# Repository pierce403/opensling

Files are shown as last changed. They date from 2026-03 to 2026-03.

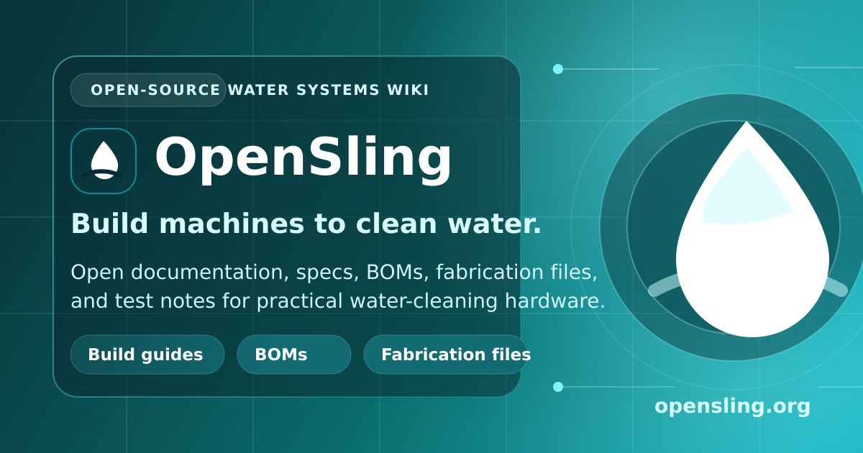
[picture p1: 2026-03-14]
docs/img/social-preview.png

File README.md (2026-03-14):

# OpenSling Wiki

OpenSling is an open documentation hub for designing, prototyping, and operating machines that clean water. This repo keeps the same MkDocs Material setup as `sloppy.wiki`, retargeted around modular treatment hardware, testing workflows, and field operations.

## Quick Start

```bash
source activate.sh
./serve.sh
```

The local site is served at `http://127.0.0.1:8000`.

To produce a deployable build:

```bash
./build.sh
```

## What This Wiki Covers

- treatment-train design for field-cleanable water systems
- mechanical and electrical architecture for modular treatment machines
- build guides for bench prototypes, pilot skids, and test rigs
- operational practices for sampling, maintenance, and safety
- research backlogs and sourcing notes for future iterations

## Repo Layout

- `mkdocs.yml`: site navigation, theme, and Markdown configuration
- `docs/`: wiki content and static assets
- `docs/css/custom-styles.css`: visual overrides for the OpenSling theme
- `.github/workflows/deploy.yml`: GitHub Actions deployment workflow
- `activate.sh`, `serve.sh`, `build.sh`: local development helpers

## Deployment

The workflow builds the site on every push to `main` and publishes it through the official GitHub Pages deployment flow. The intended public URL is:

`https://opensling.org`

## Licensing Model

OpenSling is meant to be copied and built from.

- documentation text, diagrams, tables, and educational media are licensed under `CC BY 4.0`
- code, scripts, configuration, and fabrication design sources are licensed under `Apache-2.0`

See `LICENSING.md`, `LICENSE`, and `LICENSE-docs.md`.

## License

Reuse is encouraged. Copy the docs, adapt them, fork the code, and build from the fabrication files within the license terms above.

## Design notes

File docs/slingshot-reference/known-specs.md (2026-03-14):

# Public Specs And Shared-Thread Notes

This page separates three different things:

1. public claims made by DEKA, Coca-Cola, Dartmouth, and WHO-linked reporting
2. working notes extracted from the shared ChatGPT thread you linked
3. OpenSling reconstruction choices made because the exact production design is not fully public

## What Is Publicly Documented

| Item | Shared-thread note | Public evidence | Assessment |
|---|---|---|---|
| Treatment method | Vapor-compression distillation / mechanical vapor recompression | DEKA says Slingshot uses <strong>vapor compression distillation</strong>.[^deka] | Verified |
| Water sources | “Any dirty water,” including sewage | Coca-Cola’s 2012 release says the system can boil and evaporate river water, ocean water, and raw sewage, then condense pure water.[^coke-2012] | Verified public claim |
| Output | Around <strong>1000 L/day</strong> or <strong>10 gal/hour</strong> | Coca-Cola’s 2012 release and Dartmouth’s 2014 article both repeat about <strong>10 gallons of clean water an hour</strong>; Coca-Cola also states <strong>up to 300,000 liters per year</strong>.[^coke-2012][^dartmouth] | Verified public claim |
| Power draw | Roughly <strong>500 W to under 1 kW</strong> | Dartmouth and Coca-Cola both say <strong>less than 1 kW</strong>; the shared thread also mentioned a secondary-report figure of <strong>500 W</strong>.[^coke-2012][^dartmouth][^share] | `<1 kW` is public; `500 W` should be treated as secondary-report territory |
| Physical scale | About the size of a mini-bar fridge | Dartmouth describes it as equal to a hotel mini-bar fridge.[^dartmouth] | Verified public claim |
| Maintenance posture | Few moving parts, low ongoing maintenance | Dartmouth and DEKA describe low moving-part count and low maintenance needs.[^dartmouth][^deka] | Verified public claim |
| Core evaporator geometry | Copper tubes with plastic dowels making a thin film | DEKA’s public Slingshot page states that the evaporator uses copper tubes with plastic dowels to form a thin film.[^deka] | Verified |
| Pressure lift | Compressor raises steam from <strong>7 psi to 9 psi</strong> | DEKA states this directly on the public Slingshot page.[^deka] | Verified |
| Power-source flexibility | Grid, batteries, solar, or Stirling generation | Coca-Cola’s 2012 release explicitly mentions grid, batteries, solar cells, and DEKA’s Stirling generator powered by biogas.[^coke-2012] | Verified public claim |

## What The Shared Thread Added

The shared thread is useful because it pushed the public record into a more build-oriented interpretation:

- It identified the Slingshot concept as a <strong>water-vapor heat pump</strong>, not simple one-pass boiling.
- It treated the pressure lift as a <strong>small differential</strong> that makes latent-heat recycling plausible.
- It emphasized a <strong>counterflow heat exchanger</strong>, <strong>mist elimination before compression</strong>, and <strong>blowdown handling</strong> as essential pieces of the open design.[^share]
- It argued that an exact under-`$2000`, full-scale clone is not credible, but a lower-throughput open reference machine is more realistic.[^share]

## Where The Shared Thread Was Inference

Some details in the thread are best treated as engineering hypotheses, not verified Slingshot facts:

| Thread claim | Why it matters | Current status |
|---|---|---|
| Regenerative blower as the default compressor | Drives motor selection, noise, and moisture tolerance | Reasonable inference, but not fully confirmed as the only public production implementation |
| 1.5-2 psi preferred differential across the blower | Critical for compressor sizing | Supported by patent-family reasoning in the thread, but not stated on DEKA’s public marketing page |
| Three parallel 100 ft stainless coils in a pressurized shell | Strongly shapes the open build | This is an OpenSling design proposal, not a public Slingshot bill of materials |
| 600-800 L/day baseline, 1000 L/day stretch for a practical open build | Useful for scoping fabrication and testing | OpenSling design target, not a historical Slingshot spec |

## OpenSling Position

OpenSling is not pretending to possess the hidden factory drawings for Slingshot. The approach here is:

1. take the publicly documented mechanism seriously
2. preserve only the parts that are actually evidenced
3. make reconstruction choices explicit
4. publish enough design detail that another builder can improve the system

## Source Notes

[^deka]: [DEKA Slingshot page](https://dekaresearch.com/slingshot/).
[^coke-2012]: [Coca-Cola Announces Long-Term Partnership with DEKA R&D to Help Bring Clean Water to Communities in Need, September 25, 2012](https://investors.coca-colacompany.com/news-events/press-releases/detail/333/coca-cola-announces-long-term-partnership-with-deka-rd-to-help-bring-clean-water-to-comm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).
[^dartmouth]: [One Man’s Attempt to Solve the World’s Water Problem, Dartmouth, August 27, 2014](https://home.dartmouth.edu/news/2014/08/one-mans-attempt-solve-worlds-water-problem).
[^share]: [Shared ChatGPT conversation: “Slingshot Water Distillation Design”](https://chatgpt.com/share/69b4a167-cdac-8003-a53a-c5b64e4274a3).

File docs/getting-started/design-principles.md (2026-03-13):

# Design Principles

These principles are intended to keep the project grounded when design choices start multiplying.

## Core Rules

| Principle | What it means in practice |
|---|---|
| Modular | Each treatment function should be swappable without rebuilding the whole machine. |
| Measurable | Every stage needs inlet and outlet observations, not just faith in the component label. |
| Repairable | A field operator should be able to open, clean, and replace common wear items quickly. |
| Honest about limits | If a module only handles turbidity and sediment, document that clearly. |
| Energy-aware | Power budgets matter, especially for remote or solar-backed deployments. |
| Safe by default | Pressure, electricity, UV exposure, and biohazard handling need explicit safeguards. |

## Preferred Patterns

- clear plumbing runs over tightly packed assemblies
- common voltages and connectors over custom one-off wiring
- sample ports before and after major treatment stages
- consumables that can be sourced from multiple vendors
- documentation that states the source-water scenario up front

## Avoid

- hidden dependencies between modules
- treatment claims without a validation plan
- filter stacks that are impossible to inspect or clean
- electronics mounted where leaks naturally drain
- ambiguous versioning of mechanical assemblies

## Definition of Done

A subsystem is ready to share when it has:

- a purpose statement
- a schematic or plumbing map
- a bill of materials or sourcing path
- operating assumptions
- failure modes worth watching
- at least one measurable success criterion

## Design Review Questions

Before adopting a new concept, answer these directly:

1. Which contaminant class is this stage meant to reduce?
2. What measurement shows whether it is working?
3. What fouls or wears first?
4. What does service look like after 50 hours, 200 hours, and one bad day in the field?
5. Can a contributor reproduce the design without asking the original builder?

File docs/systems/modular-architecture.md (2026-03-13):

# Modular Architecture

OpenSling treats a water-cleaning machine as a chain of interfaceable modules. Each module should have a clear role, expected inlet conditions, and a bounded maintenance story.

## Reference Modules

| Module | Purpose | Typical interfaces |
|---|---|---|
| Intake | draw from source while excluding gross debris | hose, foot valve, coarse screen |
| Solids module | remove heavy particulate load | reservoir, cyclone, drain loop |
| Fine filtration module | lower suspended solids | filter housings, differential pressure ports |
| Polishing module | adsorption or chemistry-specific treatment | inline canister, bypass manifold |
| Disinfection module | reduce biological load | UV chamber or chemical dosing zone |
| Controls module | coordinate sensors, pumps, alarms, logs | low-voltage power, I/O harness |
| Power module | supply and protect electrical loads | battery, DC bus, charging input |

## Interface Contract

Every module page should eventually define:

- flow range
- pressure range
- electrical needs
- service interval
- failure signals
- acceptable upstream and downstream conditions

## Packaging Advice

- keep the dirty path and clean path visually distinct
- mount service items where they can be replaced without pulling other modules
- place drains and flush points intentionally
- leave physical room for instrumentation upgrades

## Versioning

Use simple revision labels on assemblies and manifolds. If a field note mentions "pilot skid rev B", the plumbing map should make that traceable.

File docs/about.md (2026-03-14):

# About OpenSling

OpenSling is a working wiki for people building machines that clean water. The project is opinionated in one useful way: hardware ideas are only valuable when they can be documented, instrumented, tested, serviced, and improved in public.

## What the Project Optimizes For

- modular treatment systems instead of monolithic machines
- straightforward plumbing, wiring, and maintenance access
- explicit treatment claims tied to measurement plans
- build notes that future contributors can reproduce without oral history

## What Lives Here

This repository holds:

- design notes for treatment architecture
- build guides for prototype and pilot hardware
- operations playbooks for testing, maintenance, and safety
- research backlogs for unresolved engineering questions

## What It Does Not Claim

OpenSling does not assume that one hardware stack works for every water source. Different contaminant loads require different treatment steps, and any potable-water use case needs appropriate validation and local compliance review.

## Stack

The wiki keeps the same underlying structure as `sloppy.wiki`:

- MkDocs
- Material for MkDocs
- GitHub Actions deployment
- lightweight shell helpers for local setup, serving, and builds

## Contribution Model

The expected contribution style is simple:

1. document the problem and source-water assumptions
2. document the build or operational change
3. attach measurements, photos, or failure notes
4. leave the next person with enough context to continue

## Reuse And Licensing

OpenSling is meant to be copied.

- documentation text, diagrams, tables, and educational media are licensed under `CC BY 4.0`
- code, scripts, configuration, and fabrication design sources are licensed under `Apache-2.0`

If you want to copy pages into another wiki, translate them, print them for a workshop, adapt them into a build manual, or fork the repo to continue the engineering work, this project is set up to allow that. See [Licensing](getting-started/licensing.md).

Project source: [github.com/pierce403/opensling](https://github.com/pierce403/opensling)

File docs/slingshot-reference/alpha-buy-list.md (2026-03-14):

# Alpha Buy List And Missing Pieces

`BOM-ALPHA-2026-03-13A`

This page is the current builder-facing purchasing path for the first OpenSling distiller alpha. It is a bench-oriented, non-potable, low-pressure reference build, not a production machine and not a certified drinking-water product.

Price snapshot date: **March 13, 2026**  
Currency: **USD**  
Prices below exclude shipping, tax, duties, and any bulk-order discounts.

## Scope Of This BOM

This revision assumes:

- gravity feed or a simple elevated source tank during first commissioning
- `1.5 in.` sanitary clamp hardware on the external low-pressure wet loop
- manual logging during first clean-water runs
- non-pressure printed parts coming from the current repo fabrication pack

This revision does **not** assume:

- a finalized pressure-shell weldment
- a finalized internal tube bundle or film-forming insert geometry
- a code-stamped vessel relief package
- a finalized heater mount or control enclosure
- a finalized compressor power architecture

## Build Path

1. Order the `buy now` parts on this page.
2. Build the frame and accessible low-pressure plumbing around those parts.
3. Print the current non-pressure repo parts from the [Fabrication Pack](fabrication-pack.md).
4. Freeze the pressure-core geometry and sensor-port pattern.
5. Only then order the `hold until geometry freeze` items.
6. Commission with clean water first, then move to dirty-water testing.

## Buy Now

These parts are useful even if the pressure core changes later. They are the lowest-regret purchases in the repo right now.

| Item | Example source | Qty | Unit price | Extended | Why this is low-regret |
|---|---|-----|---|---|---|
| Frame channel, 10 ft, 12 ga | [Superstrut ZA1200HS-10](https://www.homedepot.com/p/Superstrut-10-ft-12-Gauge-Half-Slotted-Metal-Framing-Strut-Channel-in-Gold-Galvanized-ZA1200HS-10-ZA1200HS-10/100125003) | 4 | $43.65 | $174.60 | Gives a serviceable bench frame before the wet core is frozen. |
| Portable inline GFCI | [ELEGRP G20CA-2FT](https://www.homedepot.com/p/ELEGRP-2-ft-15-Amp-In-Line-Self-Test-Automatic-Reset-Portable-GFCI-Plug-with-3-Outlet-Cord-Yellow-G20CA-2FT/320391610) | 1 | $33.60 | $33.60 | Mandatory bench-power protection for early heated runs. |
| Sanitary tee, `1.5 in.` clamp x clamp x clamp | [Hamby tee](https://hambydairysupply.com/1-5-tee-clamp-x-clamp-x-clamp-stainless-steel/) | 2 | $52.00 | $104.00 | Useful for drain, demister, and sample-routing experiments. |
| Sanitary spool, `1.5 in.` x `6 in.` | [Hamby spool tube](https://hambydairysupply.com/1-5-inch-tubing-x-6-inch-length-sanitary-spool-tube/) | 4 | $34.60 | $138.40 | Flexible straight sections for mock-up and rebuilds. |
| Butterfly valve, `1.5 in.` clamp x clamp | [Hamby butterfly valve](https://hambydairysupply.com/1-5-inch-butterfly-valve-clamp-x-clamp/) | 2 | $79.99 | $159.98 | Useful for manual isolate/drain work even if the final core changes. |
| Basic sanitary clamp, `1.5 in.` | [Hamby clamp](https://hambydairysupply.com/1-5-basic-triclamp-style-pipeline-clamp/) | 12 | $8.15 | $97.80 | Core commodity hardware for any `1.5 in.` sanitary mock-up. |
| Silicone flange gasket, `1.5 in.` | [Hamby silicone gasket](https://hambydairysupply.com/1-5-inch-clamp-silicone-flange-gasket/) | 20 | $1.99 | $39.80 | Better high-temperature margin than cheap Buna placeholders. |
| Clamp x `1.5 in.` male NPT adapter | [Hamby adapter](https://hambydairysupply.com/1-5-inch-clamp-x-1-5-male-national-pipe-thread-adapter/) | 2 | $48.00 | $96.00 | Bridges sanitary sections to utility plumbing without locking the final shell design. |
| End cap with pipe for `3/4 in.` transfer hose | [Hamby hose end cap](https://hambydairysupply.com/end-cap-with-pipe-for-3-4-inch-transfer-hose/) | 2 | $24.88 | $49.76 | Useful for feed/product routing and temporary reservoir work. |
| `3/4 in.` transfer hose | [Hamby transfer hose](https://hambydairysupply.com/3-4-inch-outlet-transfer-hose/) | 10 ft | $16.00/ft | $160.00 | Good for cool-side feed, drain, and product routing. Do not treat it as a steam-hose substitute. |
| Mechanical pressure gauge, `0-30 psi` | [AutomationDirect G15-BD30-8CB](https://www.automationdirect.com/pn/G15-BD30-8CB) | 3 | $11.50 | $34.50 | Cheap enough to put on shell, suction, and discharge during manual commissioning. |
| Conductivity/TDS/temperature tester | [Milwaukee EC60 PRO](https://milwaukeeinstruments.com/EC60-PRO-Waterproof-EC-TDS-Temperature-Tester) | 1 | $77.90 | $77.90 | Fast screening tool for product-water trends during alpha testing. |
| Conductivity calibration solution | [Milwaukee MA9065](https://milwaukeeinstruments.com/MA9065-230ml-1413-uS-cm-Conductivity-Calibration-Solution) | 1 | $16.70 | $16.70 | Keeps the EC/TDS tester honest. |
| Compact float switch | [AutomationDirect FLS-HM-100](https://www.automationdirect.com/pn/FLS-HM-100) | 1 | $25.00 | $25.00 | Simple feed-tank low-level interlock before the full controls stack exists. |

**Buy-now subtotal:** **$1,208.04**

## Hold Until Geometry Freeze

These parts are plausible candidates, but the repo is not ready to tell someone to order them blindly.

| Item | Example source | Qty | Unit price | Hold reason |
|---|---|-----|---|---|
| Regenerative blower, `0.5 hp`, `52 cfm`, `43 in. wc` | [GAST 33K820](https://www.grainger.com/product/GAST-Regenerative-Blower-33K820) | 1 | $1,298.35 | Current readily priced candidate is `208-230/460 VAC` three-phase. Do not buy until power architecture and operating point are frozen. |
| Blower-side relief valve | [GAST AJ496 / Grainger 860DM9](https://www.grainger.com/product/GAST-Pressure-Relief-Valve-860DM9) | 1 | $414.35 | Only relevant if the matching blower is chosen. This is not a substitute for a code-appropriate vessel PSV. |
| Temperature controller | [AutomationDirect SL4824-RR](https://www.automationdirect.com/pn/SL4824-RR) | 1 | $125.00 | Useful, but heater style and control architecture are not frozen yet. |
| RTD probe, `Pt100`, `12 in.` probe, `1/2 in.` NPT | [AutomationDirect RTD1-C12-01](https://www.automationdirect.com/pn/RTD1-C12-01) | 3 | $103.00 | Port depth and exact insertion lengths are not frozen. |
| DIN solid-state relay, `40 A` | [AutomationDirect GRSH-40-60-D-0-0](https://www.automationdirect.com/pn/GRSH-40-60-D-0-0) | 1 | $108.00 | Only buy after the heater current, enclosure, and cooling arrangement are defined. |
| Maintained emergency-stop operator | [AutomationDirect AR22Q2R-01R](https://www.automationdirect.com/pn/AR22Q2R-01R) | 1 | $29.00 | Good part, but the panel layout and final dry-zone build are still open. |

**Hold subtotal:** **$2,283.70**

## Missing Pieces

These are not just “shopping TBD” items. They are actual design gaps in the current repo.

| Missing piece | Why it is missing | What unblocks it |
|---|---|---|
| Pressure-shell drawing | No validated shell diameter, wall thickness, ferrule pattern, or weld notes are published yet. | Freeze core geometry and publish a pressure-boundary drawing set plus hydrotest target. |
| Tube bundle and insert geometry | The repo explains the thin-film concept, but it does not yet define tube count, length, insert material, or cleaning method. | Bench heat-transfer and fouling tests on one or two candidate bundle layouts. |
| Startup heater package | Watt density, mount style, and material compatibility are still open. | Freeze shell geometry and pick a heater that will not scorch or overstress the wall. |
| Vessel overpressure protection | There is no final PSV spec or setpoint tied to a validated pressure boundary. | Complete pressure-boundary calculations and select a code-appropriate relief path. |
| Final compressor choice | Public Slingshot pressure numbers exist, but the open build still lacks a validated blower/compressor map for the chosen core. | Run a bench model or instrumented rig that confirms the needed pressure lift and vapor flow. |
| Sensor-port pattern | Gauge ports, thermowells, and sample ports are still described conceptually instead of dimensionally. | Publish a port map with thread standards and no-tool service access notes. |
| Electrical panel and wiring | There is no finished wiring diagram, enclosure cut sheet, or field-safe service layout. | Freeze the heater, blower, sensor count, and shutdown chain. |
| Potable claim pathway | Distillation helps, but the repo does not yet define validation, post-treatment, or source-specific test criteria. | Add a commissioning and validation protocol with contaminant-specific testing rules. |
| Feed pre-strainer package | The repo references coarse pre-straining, but it does not yet freeze the micron target, housing size, or whether the strainer sits before or after any lift pump. | Pick the alpha source-water envelope and publish the dirty-side plumbing layout. |
| Full fastener list | The repo does not yet define the exact frame dimensions, brackets, casters, or panel mounts. | Freeze the frame layout and publish a frame drawing or cut list. |

## What You Can Fabricate From The Repo Today

The current repo can already generate these custom **non-pressure** parts:

- control panel blank
- triple hose separator
- blower mount spacer
- demister endcap
- dual cable cleat

Those files live in the [Fabrication Pack](fabrication-pack.md). They are useful, but they do **not** close the pressure-core, heater, or electrical gaps listed above.

## Why The Vendor Mix Looks Uneven

This BOM is intentionally “Amazon or whatever,” not “Amazon only.” The current picks skew toward:

- Home Depot for bench-power safety and basic frame stock
- Hamby for sanitary dairy-process hardware that is easy to reconfigure
- AutomationDirect for controls and instrumentation
- Milwaukee for a simple field-grade conductivity screen
- Grainger for industrial blower candidates

That mix is deliberate. The goal is not retail convenience. The goal is to make the first alpha build more likely to work.

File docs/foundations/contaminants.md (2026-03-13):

# Contaminants and Constraints

Water-cleaning machines fail when the design ignores what is actually in the water. Start by classifying the source, then choose treatment stages that target the relevant loads.

## Major Contaminant Classes

| Class | Examples | Typical consequence | Common responses |
|---|---|---|---|
| Gross debris | leaves, sand, fibers, trash | pump wear, clogs, false sensor readings | screens, settling, sump design |
| Suspended solids | silt, clay, rust, organic fines | turbidity, fouling, shortened filter life | settling, hydrocyclones, cartridge or membrane filtration |
| Biological load | bacteria, protozoa, algae | health risk, slime formation, odor | disinfection, fouling control, storage hygiene |
| Dissolved organics | tannins, oils, industrial residues | taste, odor, membrane stress, uncertain toxicity | activated carbon, specialized media, source-specific analysis |
| Dissolved salts and metals | hardness, arsenic, lead, nitrate | chemistry limits not solved by simple filters | source-specific treatment such as ion exchange or membranes |

## Constraints That Change the Machine

The right treatment stack depends on more than contamination alone:

- available power and duty cycle
- target flow rate
- allowable maintenance interval
- operator skill level
- local availability of replacement parts
- whether the output is for wash water, process water, or potential drinking use

## Source Characterization Checklist

- identify the water source and collection method
- record visible solids, color, odor, and seasonality
- estimate expected flow range
- note likely upstream contamination sources
- define the use case for treated water
- decide what must be measured at minimum

!!! warning
    Do not assume "looks clear" means "safe." Visual improvement and microbial safety are separate questions.

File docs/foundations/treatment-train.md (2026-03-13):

# Treatment Train

A treatment train is a sequence of modules, each doing one job well enough that the next stage can work reliably. OpenSling assumes staged treatment is easier to debug and maintain than all-in-one boxes.

## Baseline Treatment Sequence

1. **Intake and exclusion**: keep large debris and air ingestion out of the pump path.
2. **Bulk solids reduction**: remove heavy particulate load early to protect downstream stages.
3. **Fine filtration**: reduce suspended solids to a level the final treatment stages can tolerate.
4. **Conditioning or adsorption**: use when dissolved contaminants, taste, or odor matter.
5. **Disinfection**: reduce biological risk with a method matched to flow, clarity, and power.
6. **Protected storage**: prevent recontamination after treatment.

## Why the Order Matters

Disinfection works better when turbidity is already reduced. Carbon lasts longer when solids are already managed. Pumps and sensors behave better when intake debris is controlled. The sequence is not arbitrary.

## Module Selection Questions

| Stage | Decide this first | Typical options |
|---|---|---|
| Intake | How dirty is the source mechanically? | basket strainer, screened foot valve, settling inlet |
| Solids removal | Is the load mostly heavy grit or fine suspended solids? | settling tank, swirl separator, hydrocyclone, bag filter |
| Fine filtration | What pressure drop and consumable budget are acceptable? | sediment cartridges, membrane modules |
| Adsorption | Are organics, chlorine byproducts, or odors a concern? | activated carbon block, granular carbon |
| Disinfection | What contact time and power budget are available? | UV-C, chlorination, ozone in specialized cases |

## Design Hint

Place sample points and pressure gauges around the stages that are most likely to foul. A treatment train without observability becomes guesswork fast.

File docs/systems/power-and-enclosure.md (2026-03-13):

# Power and Enclosure

The machine enclosure and power system decide whether a design survives transport, weather, and operator abuse. Treat them as first-class engineering problems.

## Power Architecture

Start with a written list of loads and duty cycles:

- pumps
- controls and sensors
- UV or other disinfection loads
- valves or actuators
- communication hardware

## Practical Defaults

- use a common DC distribution voltage where possible
- separate noisy motor power from sensitive sensor wiring
- fuse modules individually
- label every connector that might be unplugged in the field

## Enclosure Design Rules

| Rule | Reason |
|---|---|
| Keep electronics above probable leak paths | water always finds the lowest cable loop |
| Provide deliberate cable strain relief | transport vibration is unforgiving |
| Leave service clearance around filter housings | cartridge changes are routine, not edge cases |
| Vent or manage heat intentionally | sealed boxes and UV supplies can run hot |

## Environmental Considerations

- sun exposure and enclosure temperature
- splash, rain, and hose-down events
- mud and sediment on moving parts
- transport shock
- operator access with gloves or wet hands

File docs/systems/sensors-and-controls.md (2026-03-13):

# Sensors and Controls

Without instrumentation, you cannot tell whether a machine improved water quality or just moved the problem downstream.

## Baseline Sensor Set

| Sensor | Why it matters | Placement |
|---|---|---|
| Flow | verifies throughput and helps normalize performance | main treated-water line |
| Pressure | shows restriction and fouling | before and after filters |
| Tank level | protects pumps and supports automation | feed and clean tanks |
| Turbidity or optical proxy | tracks solids reduction trends | inlet and post-filtration |
| Conductivity or TDS proxy | flags dissolved-load changes | source and product water when relevant |
| Temperature | affects UV performance, battery behavior, and process notes | enclosure and water stream |

## Control Goals

The first control layer should be boring and robust:

- prevent dry running
- shut down on dangerous overpressure
- log runtime and fault states
- expose a manual override for service work
- leave room for future telemetry without depending on it

## Logging

At minimum, log:

- timestamps
- pump runtime
- fault events
- filter differential pressure
- measured or estimated treated volume

## Alarm Philosophy

Good alarms are actionable. Avoid vague indicators like "service soon" unless they map to a clear threshold such as pressure rise, runtime hours, or UV lamp age.

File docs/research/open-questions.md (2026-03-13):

# Open Questions

This page tracks engineering questions that should turn into experiments, not endless discussion.

## Current Backlog

- How much upstream solids reduction is worth the added bulk before cartridge life gains flatten out?
- Which pump style gives the best balance of suction tolerance, serviceability, and power draw for the pilot skid?
- What minimal field instrumentation gives enough signal to predict fouling before throughput collapses?
- Which treatment stages deserve bypass loops for comparative testing?
- What enclosure layout best separates wet maintenance from controls access?

## Converting Questions Into Work

For each question, define:

- the hypothesis
- the metric
- the test setup
- the run length
- the decision that will be made afterward

## Good Example

Instead of asking "Is this filter better?", ask:

> Does adding a cyclone-style pre-separation stage increase treated volume before a 5 micron cartridge reaches the service threshold?

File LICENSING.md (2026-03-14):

# Licensing

OpenSling uses a simple split-license model so reuse is obvious:

- Documentation text, diagrams, tables, and educational media are licensed under `CC BY 4.0` unless a page says otherwise.
- Code, scripts, configuration, workflows, and fabrication design sources are licensed under `Apache-2.0` unless a file says otherwise.

Practical rule:

- if you want to copy, translate, print, remix, or republish the written documentation, you can do that under `CC BY 4.0`
- if you want to fork the code, scripts, CAD, or fabrication files, you can do that under `Apache-2.0`

Repository references:

- `LICENSE`: Apache-2.0 text for code and design-source artifacts
- `LICENSE-docs.md`: CC BY 4.0 notice for documentation content

If a stricter or different license applies to a specific asset, that asset should say so explicitly in its file header or adjacent README.

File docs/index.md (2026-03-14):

# OpenSling Wiki

<div class="hero">
  <h1>Slingshot proved the signal. OpenSling is the open-source follow-through.</h1>
  <p>Dean Kamen’s Slingshot showed that low-power vapor-compression distillation could turn awful water into clean output. The public rollout never became the open, durable, globally reproducible hardware movement the problem still demands. OpenSling exists to publish the designs, assumptions, fabrication files, test plans, and failure notes anyway.</p>
</div>

<div class="signal-strip">
  <div class="signal-card">
    <strong>2006</strong>
    <span>Slingshot enters public view through Dean Kamen’s TED-era push.[^deka-history]</span>
  </div>
  <div class="signal-card">
    <strong>2012-2015</strong>
    <span>Coca-Cola and DEKA announce rollout targets, pilots, EKOCENTER scaling, and emergency deployments.[^coke-2012][^coke-2013][^deka-history]</span>
  </div>
  <div class="signal-card">
    <strong>2024</strong>
    <span>WHO and JMP still report extreme global burdens from unsafe water, poor sanitation, weak hygiene, cholera, schistosomiasis, and malaria-linked infrastructure stress.[^malaria-2025][^jmp-2025][^who-wash-2026][^who-drinking-water][^who-cholera][^who-schisto]</span>
  </div>
</div>

## Brief History Of Slingshot

The public Slingshot story is impressive and frustrating at the same time.

| Date | Publicly documented milestone | Why it mattered |
|---|---|---|
| 2006-2008 | Slingshot became widely known as a compact distillation machine aimed at making potable water from dirty sources. | It reframed water treatment as rugged field hardware instead of fragile aid equipment. |
| 25 September 2012 | Coca-Cola and DEKA announced a long-term partnership to deploy Slingshot systems in communities with limited potable water access.[^coke-2012] | This was the clearest public scale-up signal: up to 300,000 liters per unit per year, about 10 gallons per hour, and less than 1 kW of electricity. |
| 24 September 2013 | Coca-Cola’s EKOCENTER partnership expanded the ambition to 20 countries by the end of 2015, 1,500-2,000 units, and 500 million liters of safe drinking water.[^coke-2013] | Slingshot looked like it might become infrastructure instead of a demo. |
| 2011-2014 | DEKA’s own site documents pilots in Ghana, Paraguay, and South Africa.[^deka-history] | There was real field activity, not just stage presentations. |
| 2015 | DEKA says Slingshot units were deployed in Dominica after Tropical Storm Erika and provided water until local service returned.[^deka-history] | This showed emergency-response value. |
| 15 June 2016 | Coca-Cola’s flagship Rwanda EKOCENTER release highlighted Pentair reverse-osmosis units, not Slingshot, for safe-water production.[^coke-rwanda-2016] | The public story appears to shift from Slingshot-centered rollout to broader EKOCENTER operations with other water technologies. |

<div class="callout-panel">
  <strong>Inference, not a confirmed shutdown:</strong> as of <strong>March 13, 2026</strong>, the public Slingshot rollout trail I could verify is strongest from 2012 through 2015. Later public EKOCENTER material is still active, but the specific Slingshot-centered scale story becomes much harder to verify in public sources.[^coke-rwanda-2016][^deka-history]
</div>

## Why The Urgency Is Worse Now

OpenSling is not being built in a calmer world. The burden is still enormous:

| Problem | Latest sourced figure | Why it matters for OpenSling |
|---|---|---|
| Malaria | WHO estimates <strong>282 million malaria cases</strong> and <strong>610,000 deaths</strong> in <strong>2024</strong>, about <strong>9 million more cases than 2023</strong>.[^malaria-2025] | Malaria is mosquito-borne, not water-borne, but stagnant water, weak drainage, and fragile infrastructure increase exposure and compound public-health stress. |
| Drinking water | <strong>2.1 billion</strong> people still lacked safely managed drinking water in <strong>2024</strong>, including <strong>106 million</strong> drinking untreated surface water.[^jmp-2025] | The water-access gap is still measured in billions, not edge cases. |
| Sanitation | <strong>3.4 billion</strong> people still lacked safely managed sanitation in <strong>2024</strong>, including <strong>354 million</strong> practicing open defecation.[^jmp-2025] | Water machines without sanitation awareness solve only part of the exposure chain. |
| Hygiene | <strong>1.7 billion</strong> people still lacked basic hygiene services at home in <strong>2024</strong>.[^jmp-2025] | Clean water output has to be paired with storage, handling, and hygiene practice. |
| Contaminated drinking water | WHO says at least <strong>1.7 billion</strong> people used a drinking-water source contaminated with faeces in <strong>2022</strong>, contributing to roughly <strong>505,000 diarrhoeal deaths</strong> each year.[^who-drinking-water] | This is the direct case for treatment hardware that is measurable and maintainable. |
| WASH-attributable mortality | WHO says unsafe water, sanitation, and hygiene still drive at least <strong>1.4 million preventable deaths</strong> per year.[^who-wash-2026] | The burden is still large enough to justify open infrastructure work, not just policy talk. |
| Cholera | WHO reported <strong>more than 560,000 cholera cases</strong> and <strong>over 6,000 deaths</strong> across <strong>60 countries</strong> in <strong>2024</strong>.[^who-cholera] | Outbreaks still surge where safe water and sanitation are weak. |
| Schistosomiasis | WHO estimates <strong>253.7 million</strong> people required preventive treatment in <strong>2024</strong>.[^who-schisto] | Water contact itself remains a major disease pathway in many regions. |

## Why OpenSling Exists

Slingshot proved that elegant water hardware was possible. OpenSling is here because the problem still exists and the designs still are not open enough.

<div class="feature-grid">
  <div class="feature-card">
    <h3>Open evidence</h3>
    <p>Every major claim should link back to a public source, a measurement plan, or both.</p>
  </div>
  <div class="feature-card">
    <h3>Open fabrication</h3>
    <p>Custom parts should ship with editable source files, exported meshes, and enough notes for another builder to reproduce them.</p>
  </div>
  <div class="feature-card">
    <h3>Open failure logs</h3>
    <p>Fouling, scaling, volatile carryover, leaks, and bad test results are part of the design record, not something to hide.</p>
  </div>
  <div class="feature-card">
    <h3>Open licensing</h3>
    <p>OpenSling documentation is licensed for CC BY 4.0 reuse, while code and fabrication design sources are licensed Apache-2.0. Copy it, adapt it, and build from it.</p>
  </div>
</div>

## Start Here

1. Read [Public Specs and Shared-Thread Notes](slingshot-reference/known-specs.md) to see which Slingshot details are public, which came from the shared ChatGPT thread, and which remain inference.
2. Use [Alpha Buy List and Missing Pieces](slingshot-reference/alpha-buy-list.md) to see what you can responsibly order right now and what is still undefined.
3. Use [OpenSling Assembly Overview](slingshot-reference/assembly-overview.md) for the current reference-build sequence.
4. Work through the component pages before fabricating anything pressure-bearing or potable-water-facing.
5. Treat the current design as an open engineering baseline, not a certified drinking-water product.

## Sources

[^deka-history]: [DEKA Slingshot page](https://dekaresearch.com/slingshot/).
[^coke-2012]: [Coca-Cola Announces Long-Term Partnership with DEKA R&D to Help Bring Clean Water to Communities in Need, September 25, 2012](https://investors.coca-colacompany.com/news-events/press-releases/detail/333/coca-cola-announces-long-term-partnership-with-deka-rd-to-help-bring-clean-water-to-comm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).
[^coke-2013]: [Coca-Cola Launches Global EKOCENTER Partnership to Deliver Safe Drinking Water and Basic Necessities to Rural Communities, September 24, 2013](https://investors.coca-colacompany.com/news-events/press-releases/detail/7/correcting-and-replacing-coca-cola-launches-global-ekocenter-partnership-to-deliver-safe-d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).
[^coke-rwanda-2016]: [Coca-Cola and Partners Create New Model for Social and Economic Development with Opening of Flagship EKOCENTER Site in Rwanda, June 15, 2016](https://investors.coca-colacompany.com/news-events/press-releases/detail/838/coca-cola-and-partners-create-new-model-for-social-and).
[^malaria-2025]: [WHO World malaria report 2025](https://www.who.int/teams/global-malaria-programme/reports/world-malaria-report-2025) and [WHO malaria fact sheet](https://www.who.int/news-room/fact-sheets/detail/malaria%E2%80%AF%E2%80%AF%E2%80%AF).
[^jmp-2025]: [WHO/UNICEF JMP 2025 household WASH progress report](https://washdata.org/reports/jmp-2025-wash-households) and [WHO/UNICEF summary news release, August 26, 2025](https://www.who.int/news/item/26-08-2025-1-in-4-people-globally-still-lack-access-to-safe-drinking-water---who--unicef).
[^who-drinking-water]: [WHO drinking-water fact sheet](https://www.who.int/news-room/fact-sheets/detail/drinking-water).
[^who-wash-2026]: [WHO water, sanitation, hygiene and waste strategy 2026-2035](https://www.who.int/publications/i/item/B09661).
[^who-cholera]: [WHO Global situation report for cholera, 2024](https://www.who.int/publications/i/item/who-wer10036-347-364).
[^who-schisto]: [WHO schistosomiasis fact sheet](https://www.who.int/news-room/fact-sheets/detail/schistosomiasis).

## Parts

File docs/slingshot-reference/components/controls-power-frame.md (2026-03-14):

# Controls, Power, And Frame

The machine is only useful if it can start reliably, stay inside safe limits, and be serviced in the field without guesswork.

## Shared-Thread Basis

The shared thread suggested:

- a startup heater around <strong>1200 W</strong>
- pressure gauge and thermostat coverage
- conductivity checks
- manual feed and blowdown regulation for the first low-cost build
- a frame built around service access rather than compactness for its own sake[^share]

## OpenSling Reference Choice

The current reference architecture uses:

- a welded or bolted serviceable frame
- isolated wet and dry zones
- startup heat under operator control
- basic pressure, temperature, level, and product-quality instrumentation
- emergency stop and overpressure response

## Minimum Instrument Set

| Signal | Purpose |
|---|---|
| Shell pressure | tracks core operating point |
| Compressor inlet and outlet pressure | tracks compression health |
| Feed and product temperature | tracks recovery performance |
| Tank level | prevents dry-run events |
| Product conductivity | basic screening before any stronger claims |

## Frame Rules

- keep electronics above probable leak paths
- label every service valve
- leave wrench access around unions and clamps
- make sample collection possible while the machine is running

## OpenSling Bias

Use more structure and visibility than a polished commercial box would. Open hardware wins when the next builder can understand it quickly.

[^share]: [Shared ChatGPT conversation: “Slingshot Water Distillation Design”](https://chatgpt.com/share/69b4a167-cdac-8003-a53a-c5b64e4274a3).

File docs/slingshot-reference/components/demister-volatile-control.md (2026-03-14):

# Demister And Volatile Control

A distiller that ignores droplets and volatile carryover will eventually lie to the operator. This module protects the compressor and improves output quality.

## Public And Shared-Thread Basis

The shared thread repeatedly treated mist elimination, knock-out protection, volatile management, and vent/backpressure control as required parts of a believable Slingshot-style system.[^share]

## OpenSling Reference Choice

The current open design uses:

- a removable demister cartridge or pad upstream of compression
- a knock-out volume with drain access
- a controlled vent or backpressure element
- a clear path for adding carbon vent treatment in non-potable test setups

## Why This Matters

- droplets destroy compressors
- entrained concentrate contaminates product claims
- non-condensables degrade heat transfer
- volatile organics can bypass naive “boil it and forget it” assumptions

## What To Measure

- liquid accumulation in the knock-out section
- compressor inlet humidity or condensate evidence
- vent flow behavior
- odor or carryover events in product water

## Open Safety Note

Distillation does not magically remove every volatile contaminant. If source chemistry is uncertain, do not make potable claims without source-specific testing and appropriate post-treatment.

[^share]: [Shared ChatGPT conversation: “Slingshot Water Distillation Design”](https://chatgpt.com/share/69b4a167-cdac-8003-a53a-c5b64e4274a3).

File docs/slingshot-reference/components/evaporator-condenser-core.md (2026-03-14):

# Evaporator And Condenser Core

This module is the heart of the machine. It is where the feed is lifted toward evaporation and where compressed vapor returns its latent heat by condensing.

## Public Slingshot Basis

DEKA’s public Slingshot page describes:

- preheated source water entering from the bottom
- copper tubes
- plastic dowels placed inside the tubes
- a thin water film between dowel and tube wall
- compressed steam condensing on the “cooler” tubes and driving the next evaporation step[^deka]

## OpenSling Reference Choice

The open design keeps the same functional idea but makes the implementation easier to inspect and fabricate:

| Publicly documented element | OpenSling reference choice |
|---|---|
| Copper thin-film evaporator tubes | 316L stainless tube bundle with removable flow displacers or inserts |
| Sealed proprietary module | Pressure shell with service ports, visual instrumentation, and replaceable gaskets |
| Implicit condensation on tube exterior | Explicit shell-side condenser zone with accessible sample and drain points |

## Design Requirements

- maintain a stable thin film on the hot side
- minimize dry spots and localized scaling
- maximize recoverable heat transfer area
- tolerate repeated disassembly for cleaning and redesign

## Things To Measure

- inlet feed temperature
- shell pressure
- tube-wall or near-wall temperature
- outlet concentrate temperature
- scale growth and fouling pattern

## Failure Modes

- tube fouling and scale lock
- uneven film distribution
- gasket creep during thermal cycling
- carryover caused by unstable boiling

## Open Questions

- Whether the best open version uses stainless rods, printed displacers, or hybrid inserts
- How much serviceability is lost if the bundle becomes too dense

[^deka]: [DEKA Slingshot page](https://dekaresearch.com/slingshot/).

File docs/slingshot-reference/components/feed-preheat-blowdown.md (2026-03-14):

# Feed, Preheat, And Blowdown Loop

This module decides whether the rest of the machine stays efficient or spends its life fighting cold feed and concentrated waste.

## Basis From Public Material And Shared Notes

The shared thread proposed:

- a <strong>50 µm strainer</strong>
- a tube-in-tube or similar preheater
- heat recovery from both clean product and blowdown
- a manual or semi-manual blowdown control approach for the first open build[^share]

## OpenSling Reference Choice

The reference loop includes:

- feed tank or source connection
- cleanable coarse strainer
- counterflow preheat section
- manual blowdown needle valve
- routed drains and sample points

## Design Goals

- preheat feed before it enters the core
- reject concentrated waste in a controlled way
- expose fouling behavior instead of hiding it
- make all dirty-side maintenance obvious

## Things To Measure

- feed temperature before and after preheat
- blowdown flow rate
- concentrate conductivity or salinity trend
- strainer fouling interval

## Common Failure Modes

- preheater clogging
- thermal losses in long exposed lines
- blowdown set too low, causing salt buildup
- blowdown set too high, wasting water and energy

[^share]: [Shared ChatGPT conversation: “Slingshot Water Distillation Design”](https://chatgpt.com/share/69b4a167-cdac-8003-a53a-c5b64e4274a3).

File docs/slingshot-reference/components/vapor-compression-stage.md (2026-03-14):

# Vapor Compression Stage

The vapor compression stage is what makes the energy story believable. Instead of discarding the latent heat of evaporation, the machine lifts vapor pressure and temperature slightly so condensation can reheat the next cycle.

## Public Basis

DEKA publicly states that the compressor raises the steam from <strong>7 psi to 9 psi</strong>.[^deka]

The shared thread interprets the Slingshot concept as a low-lift mechanical vapor recompression system and treats that small pressure jump as the critical reason the machine can work at low electrical input.[^share]

## OpenSling Reference Choice

For the current open build, the default assumption is a serviceable low-pressure compressor stage with:

- a side-channel or regenerative blower for the first build cycle
- upstream droplet separation
- suction and discharge temperature sensing
- suction and discharge pressure sensing
- vibration isolation mounts

## Why This Module Matters

If the compressor is oversized, the system wastes power and overheats the loop. If it is undersized, the temperature lift is too small and throughput collapses.

## What To Watch

- suction wetness or droplet carryover
- discharge temperature rise
- blower power draw
- pressure differential stability at steady state
- acoustic signature changes that suggest fouling or water ingestion

## Failure Modes

- moisture ingestion damaging the blower
- thermal overload from poor venting or bad operating point
- unstable pressure oscillation when boiling behavior changes

## Design Rule

Protect the compressor from liquid. A cheap compressor becomes an expensive bottleneck once it sees droplets instead of dry vapor.

[^deka]: [DEKA Slingshot page](https://dekaresearch.com/slingshot/).
[^share]: [Shared ChatGPT conversation: “Slingshot Water Distillation Design”](https://chatgpt.com/share/69b4a167-cdac-8003-a53a-c5b64e4274a3).

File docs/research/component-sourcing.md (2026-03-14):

# Component Sourcing

Component selection should support iteration speed and field maintenance, not just nominal spec-sheet performance.

## Sourcing Heuristics

- prefer parts with multiple suppliers
- avoid housings and cartridges that lock the project into one brand
- record connector types, thread standards, and sealing materials
- note lead times for items that can block rebuilds

## Priority Categories

| Category | What to capture |
|---|---|
| Pumps | flow range, suction behavior, service kits, voltage |
| Filters and housings | micron rating, pressure drop, seal material, replacement cost |
| Sensors | interface type, calibration needs, ingress protection |
| Fittings and valves | thread standard, body material, service access |
| Power components | charging profile, fuse strategy, field replaceability |

## Vendor Notes

Keep sourcing notes practical:

- what arrived quickly
- what was packaged poorly
- what had misleading documentation
- what worked but was painful to service

The goal is not a shopping catalog. It is a memory system for future build decisions.

## Current Distiller Snapshot

The current dated distiller purchasing snapshot lives in [Alpha Buy List and Missing Pieces](../slingshot-reference/alpha-buy-list.md).

When updating that page:

- date-stamp the BOM revision
- record whether a line item is `buy now`, `hold`, or `missing`
- separate low-regret commodity parts from geometry-dependent hardware
- treat shipping and tax as separate from the published subtotal

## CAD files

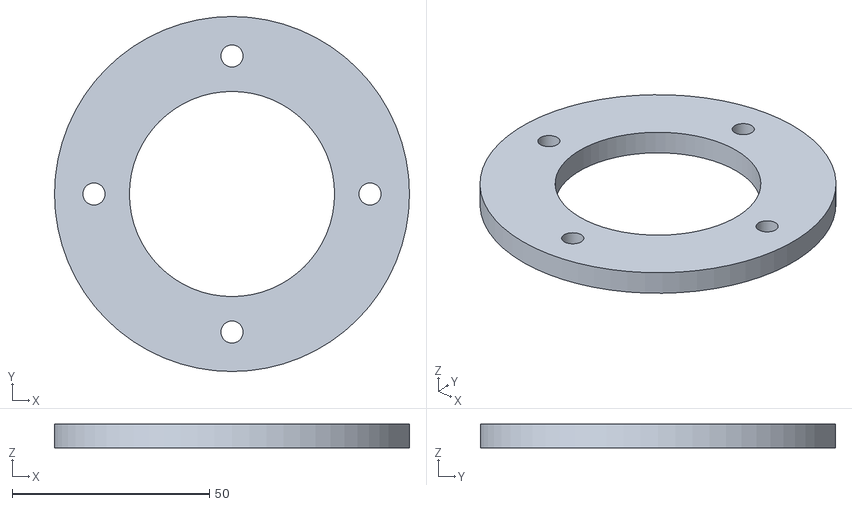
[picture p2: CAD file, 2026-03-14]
fabrication/stl/demister_endcap.stl
90.0 x 90.0 x 6.00

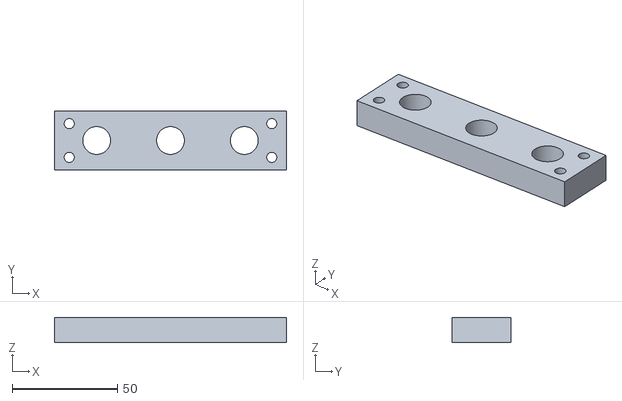
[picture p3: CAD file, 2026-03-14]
fabrication/stl/triple_hose_separator.stl
110.0 x 28.0 x 12.0

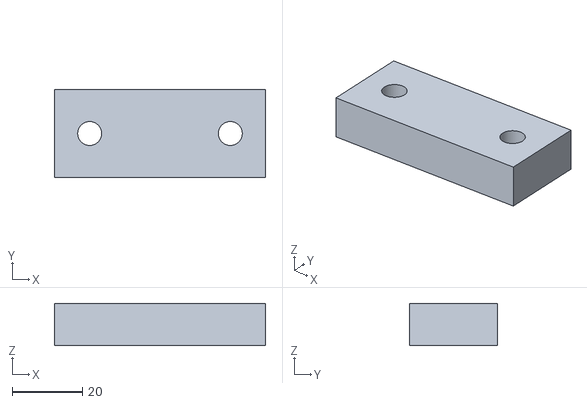
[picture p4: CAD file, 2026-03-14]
fabrication/stl/blower_mount_spacer.stl
60.0 x 25.0 x 12.0

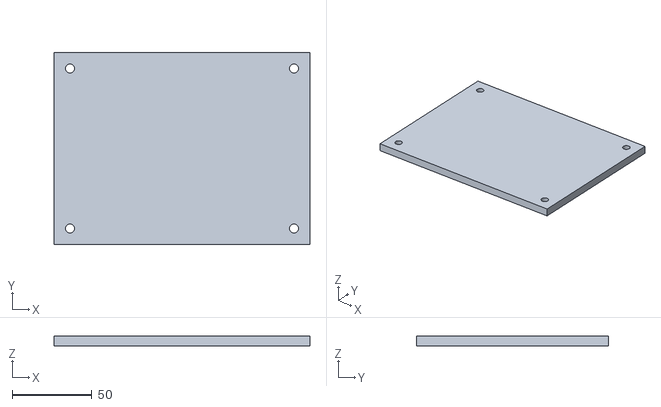
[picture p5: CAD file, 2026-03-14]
fabrication/stl/control_panel_blank.stl
160.0 x 120.0 x 6.00

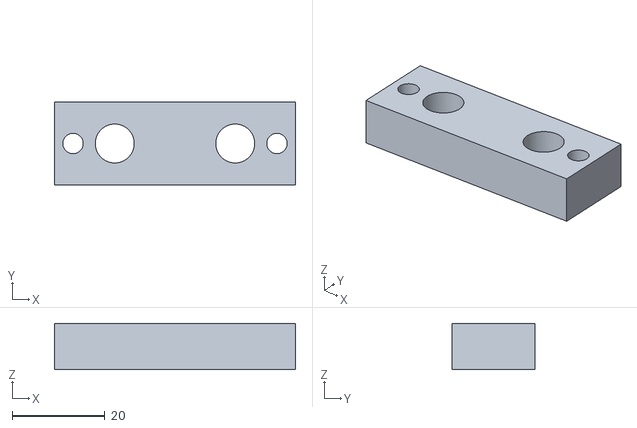
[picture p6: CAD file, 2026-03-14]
fabrication/stl/dual_cable_cleat.stl
52.0 x 18.0 x 10.0

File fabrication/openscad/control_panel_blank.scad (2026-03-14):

$fn = 64;

difference() {
  cube([160, 120, 6], center = true);
  for (x = [-70, 70], y = [-50, 50]) {
    translate([x, y, 0]) cylinder(h = 12, r = 2.8, center = true);
  }
}

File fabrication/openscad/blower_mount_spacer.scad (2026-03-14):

$fn = 64;

difference() {
  cube([60, 25, 12], center = true);
  for (x = [-20, 20]) {
    translate([x, 0, 0]) cylinder(h = 20, r = 3.4, center = true);
  }
}

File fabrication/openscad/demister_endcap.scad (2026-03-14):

$fn = 96;

difference() {
  cylinder(h = 6, r = 45, center = true);
  cylinder(h = 12, r = 26, center = true);
  for (p = [[0, 35], [35, 0], [0, -35], [-35, 0]]) {
    translate([p[0], p[1], 0]) cylinder(h = 12, r = 2.8, center = true);
  }
}

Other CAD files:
fabrication/openscad/dual_cable_cleat.scad
fabrication/openscad/triple_hose_separator.scad

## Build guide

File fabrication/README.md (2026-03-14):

# Fabrication Pack

This directory stores the current custom-part starter pack for OpenSling.

## Scope

Included parts are limited to custom non-pressure components that support routing, mounting, guarding, or instrumentation.

Not included:

- pressure-bearing shells
- heat-exchanger metal fabrication drawings
- compressor internals
- certified mains-power assemblies

## Layout

- `openscad/`: editable reference CAD sources
- `stl/`: generated mesh exports
- `generate_assets.py`: mesh-generation script
- `requirements.txt`: Python dependencies for regeneration

## Regeneration

```bash
source ../venv/bin/activate
pip install -r requirements.txt
python generate_assets.py
```

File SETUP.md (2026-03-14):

# OpenSling Wiki Setup Notes

This file captures the initial decisions used to adapt the `sloppy.wiki` scaffold into the OpenSling project wiki.

## Current Decisions

| Item | Value | Notes |
|---|---|---|
| Site name | `OpenSling Wiki` | Public-facing wiki title |
| Tagline | `Open documentation for building machines that clean water` | Used in metadata and homepage copy |
| Repo URL | `https://github.com/pierce403/opensling` | GitHub source of truth |
| Site URL | `https://opensling.org` | Intended public URL |
| Logo path | `docs/img/logo.svg` | Simple in-repo SVG mark |
| Favicon path | `docs/img/favicon.svg` | Matching SVG favicon |
| Primary color | `teal` | Material theme token |
| Accent color | `cyan` | Material theme token |
| Default mode | Light, with dark toggle | Better for diagrams and field photos |
| Custom domain | `opensling.org` | Published through GitHub Pages |

## Content Structure

The initial documentation tree is organized around the actual work of building water-cleaning hardware:

- `getting-started/`: project scope, design rules, contributor workflow
- `foundations/`: treatment concepts and design tradeoffs
- `systems/`: architecture, controls, and packaging
- `build-guides/`: prototype, pilot, and test-rig instructions
- `operations/`: validation, maintenance, and safety
- `research/`: open questions and sourcing notes

## Local Workflow

```bash
source activate.sh
./serve.sh
./build.sh
```

The local helper scripts mirror the original template, with messages renamed for OpenSling.

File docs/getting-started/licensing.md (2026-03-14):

# Licensing

OpenSling is meant to be copied, remixed, translated, printed, taught from, and built from.

## Default Licenses

- documentation text, diagrams, tables, and educational media: `CC BY 4.0`
- code, scripts, configuration, workflows, and fabrication design sources: `Apache-2.0`

## What This Means In Practice

If you want to:

- copy a page into another wiki
- translate a build guide
- print a workshop handout
- quote sections in a report
- adapt an assembly guide for your own machine
- fork the repo and keep developing it

you can do that.

## Attribution Rule

For `CC BY 4.0` documentation reuse, give reasonable credit, link back to the license, and note major changes if you made them.

Useful references:

- [Creative Commons Attribution 4.0 International](https://creativecommons.org/licenses/by/4.0/)
- [Apache License, Version 2.0](https://www.apache.org/licenses/LICENSE-2.0)

## Scope Notes

- The Apache license text for code and design-source artifacts lives in the repo root at `LICENSE`.
- The documentation license notice lives in the repo root at `LICENSE-docs.md`.
- If a specific file or asset says something different, follow that file-specific notice.

## Project Bias

No one should hesitate to copy this material because they are worried the project is silently closed. It is not. Reuse is the point.

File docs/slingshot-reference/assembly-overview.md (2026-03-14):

# OpenSling Assembly Overview

This is a high-level assembly guide for the current OpenSling reference distiller. It is inspired by the public Slingshot mechanism, but it is not presented as a factory clone or a certified potable-water product.

## Reference Build Scope

The current reference build assumes:

- a low-pressure vapor-compression distillation loop
- aggressive heat recovery on feed, product, and blowdown streams
- a custom frame plus pressure-bearing wet hardware
- removable non-pressure custom parts for routing, guarding, mounting, and instrumentation

## Before You Build

Do not start with contaminated water. First assemble and commission with clean water so that you can:

- pressure test the shell and fittings
- validate controls and shutdown logic
- characterize leaks and parasitic heat loss
- establish baseline pressure and temperature behavior

## Builder Flow

If your goal is to actually get parts on a bench instead of just reading theory, use this order:

1. Read the [Alpha Buy List and Missing Pieces](alpha-buy-list.md).
2. Order the `buy now` parts first. Those are the lowest-regret purchases in the current repo state.
3. Print or machine the non-pressure parts in the [Fabrication Pack](fabrication-pack.md).
4. Build the frame, drains, feed-side routing, and instrument mounts before buying the pressure core.
5. Hold the expensive geometry-dependent parts until the pressure shell, heater mount, and compressor operating point are frozen.
6. Hydrotest with water before any heated or dirty-water run.

The current OpenSling docs are honest about what is still missing. That is better than pretending a pressure vessel or heater package is already settled when it is not.

## Assembly Sequence

1. **Build the frame and mounting surfaces.**
   Mount the wet section low and the controls section high. Leave service clearance around the compressor, heater, knock-out pot, and sample ports.

2. **Assemble the feed, preheat, and blowdown loop.**
   Install the feed tank, coarse strainer, preheater, blowdown needle valve, drain routing, and collection vessel before the distillation core goes in.

3. **Assemble the evaporator/condenser core.**
   Build the main pressure shell, internal tube bundle, service ports, relief provisions, and insulation interface. Pressure-bearing parts require hydrotest before thermal commissioning.

4. **Install demister and mist protection upstream of compression.**
   Add the knock-out/demister stage between the steam chest and the compressor so entrained droplets do not become compressor damage.

5. **Mount the vapor-compression stage.**
   Install the side-channel/regenerative blower or chosen compressor with isolation mounts, a short service loop, and temperature/pressure instrumentation on both sides.

6. **Route the product condensation and recovery lines.**
   Direct condensed product into clean-side tubing, then through any polishing or storage-protection steps you plan to test.

7. **Install startup heat and controls.**
   Add the startup heater, contactor or relay hardware, level sensing, pressure sensing, and emergency stop logic. Keep wet and electrical zones visually separated.

8. **Fit custom support and routing parts.**
   Install the printed guards, cable guides, hose separators, panel blanks, and mounting brackets from the [Fabrication Pack](fabrication-pack.md) only after major hardware alignment is fixed.

9. **Hydrotest and leak-check.**
   Test the pressure boundary with water, not steam, first. Record pressures, dwell times, and any gasket movement.

10. **Commission with clean water, then move to dirty-water trials.**
   Establish stable startup, steady-state compression, blowdown control, and product routing before exposing the machine to fouling loads.

## Minimum Commissioning Data

- feed, shell, and compressor pressures
- steam-side and product-side temperatures
- startup time to stable production
- blowdown rate
- product conductivity or other basic quality screen
- treated volume before noticeable fouling or drift

## Build Philosophy

The goal is not to hide complexity inside a sealed box. The goal is to create a machine that can be opened, sampled, cleaned, modified, and understood by the next builder.

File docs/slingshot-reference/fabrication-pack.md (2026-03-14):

# Fabrication Pack

The fabrication pack covers the custom <strong>non-pressure</strong> parts currently defined in the open reference build. It does <strong>not</strong> claim that the pressure shell, heat-exchanger bundle, compressor internals, or mains-power enclosure are fabrication-ready.

## What Is Included

| Part | Purpose | Files |
|---|---|---|
| Control panel blank | Generic front panel for gauges, labels, and later cutouts | `fabrication/openscad/control_panel_blank.scad`, `fabrication/stl/control_panel_blank.stl` |
| Triple hose separator | Keeps three process lines aligned and serviceable outside the hot pressure boundary | `fabrication/openscad/triple_hose_separator.scad`, `fabrication/stl/triple_hose_separator.stl` |
| Blower mount spacer | Raises or levels the compressor/blower base during fit-up | `fabrication/openscad/blower_mount_spacer.scad`, `fabrication/stl/blower_mount_spacer.stl` |
| Demister endcap | Non-pressure retainer for a removable demister cartridge concept | `fabrication/openscad/demister_endcap.scad`, `fabrication/stl/demister_endcap.stl` |
| Dual cable cleat | Strain-relieved routing for control or low-voltage sensor lines | `fabrication/openscad/dual_cable_cleat.scad`, `fabrication/stl/dual_cable_cleat.stl` |

## What Is Intentionally Not Included Yet

- pressure-shell weldments
- evaporator/condenser tube bundle metal drawings
- gasket specifications for potable certification
- mains-power enclosure cutouts and certified electrical assemblies
- any claim that the current meshes are sufficient for drinking-water deployment

## Source Of Truth

The editable source files are kept in `fabrication/openscad/`, while the exported meshes are kept in `fabrication/stl/`. STL exports can be regenerated with:

```bash
source venv/bin/activate
python fabrication/generate_assets.py
```

## Safety Boundary

These assets are for brackets, blanks, separators, and retainers. They are not substitutes for pressure-vessel design, high-temperature materials validation, or regulatory compliance.

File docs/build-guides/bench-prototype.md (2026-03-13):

# Bench Prototype

The bench prototype is the fastest way to validate the OpenSling treatment logic before committing to a field-ready chassis.

## Objective

Build a reconfigurable loop that allows quick changes to:

- intake geometry
- solids removal stage
- cartridge selection
- pressure instrumentation
- disinfection method

## Suggested Starter Stack

| Stage | Example approach |
|---|---|
| Feed | open test reservoir with screened pickup |
| Pump | 12 VDC diaphragm or centrifugal pump sized for moderate flow |
| Pre-separation | small settling chamber or cyclone test section |
| Fine filtration | clear-housing sediment cartridge |
| Polishing | optional carbon block in bypass or full-flow mode |
| Disinfection | UV chamber or placeholder spool for later comparison |

## Build Priorities

1. mount gauges before and after fine filtration
2. include sample valves at inlet, post-filtration, and final outlet
3. make drains easy to use without spraying the work area
4. label flow direction on every removable module

## Bench Success Criteria

- repeatable flow measurement
- visible and measurable change across at least one treatment stage
- easy cartridge or module swap within minutes
- logging or manual recording procedure defined before the first test

## Notes

This prototype is for process development. If the system is later aimed at potable use, validation requirements become much stricter than "it looked better on the bench."

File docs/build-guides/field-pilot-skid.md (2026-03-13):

# Field Pilot Skid

The field pilot skid packages the same treatment logic as the bench rig into a machine that can be transported, serviced, and observed during longer runs.

## Pilot Goals

- survive transport and setup without replumbing
- support repeated service cycles in one workday
- carry enough sensing to explain failures instead of hiding them
- keep dirty-side and clean-side handling physically separate

## Layout Pattern

Arrange the skid in treatment order from one side to the other:

1. intake and feed connections
2. solids handling and dirty drains
3. fine filtration and differential pressure instrumentation
4. polishing or disinfection
5. clean outlet and storage connection
6. controls and power above the wet zone

## Commissioning Checklist

- verify all hoses and unions are tightened
- flush the machine with non-critical water before first sampling
- log baseline pressures at clean-filter condition
- test dry-run and overpressure protections
- confirm sampling points are accessible with the machine operating

## Serviceability Rules

- no filter change should require moving the entire skid
- electrical panels should open without exposing wet plumbing
- common service parts should be visible at a glance
- the operator should be able to isolate modules for troubleshooting

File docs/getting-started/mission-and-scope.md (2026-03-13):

# Mission and Scope

OpenSling exists to document how to build **machines that make dirty water cleaner in a measurable way**. The emphasis is on practical systems engineering: treatment stages, component choices, testing plans, and operating procedures.

## Working Mission

Build an open, modular reference stack for water-cleaning hardware that is:

- understandable by new contributors
- instrumented enough to debug
- repairable without vendor lock-in
- explicit about source-water assumptions

## Primary Deliverables

The first version of this wiki is organized around three tangible outputs:

1. a bench prototype that is easy to modify and measure
2. a field pilot skid that packages the same logic into serviceable hardware
3. a reusable test rig for comparing pumps, filters, and treatment stages

## In Scope

- intake, pumping, plumbing, and packaging decisions
- solids removal, filtration, adsorption, and disinfection stages
- sensor selection, control logic, and data logging
- maintenance procedures and failure analysis
- documentation standards for experiments and field notes

## Out of Scope

- claims that a generic design is safe for every water source
- industrial compliance advice for specific jurisdictions
- replacing laboratory validation with informal observation

## How to Use the Wiki

If you are new:

1. start with [Design Principles](design-principles.md)
2. read the water-side context in [Contaminants and Constraints](../foundations/contaminants.md)
3. choose a system concept in [Modular Architecture](../systems/modular-architecture.md)
4. build something concrete from the [Bench Prototype](../build-guides/bench-prototype.md)

!!! note
    OpenSling treats documentation as part of the hardware. A prototype without assumptions, measurements, and failure notes is incomplete.

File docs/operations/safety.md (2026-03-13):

# Safety

Water treatment hardware mixes electricity, pressure, biological exposure, and sometimes UV or chemicals. Treat safety as design work, not a footnote.

## Core Hazards

| Hazard | Typical source | Control approach |
|---|---|---|
| Electrical shock | wet connectors, damaged insulation, poor grounding | sealed connectors, strain relief, isolation, inspections |
| Pressure release | clogged filters, dead-headed pumps, trapped air | relief paths, gauges, shutdown logic |
| Biological exposure | raw water handling, sludge removal, contaminated surfaces | gloves, containment, cleaning procedures |
| UV exposure | open or damaged UV chamber | shielding, interlocks, service lockout |
| Chemical mishandling | disinfectants or cleaning agents | labeling, PPE, storage discipline |

## Operator Rules

- isolate power before opening electrical enclosures
- depressurize wet-side modules before service
- treat sludge and dirty consumables as contaminated waste
- document any bypass or safety override used during testing

## Shop and Field Readiness

Before running a machine outside the bench:

- verify emergency shutdown behavior
- check that all drains route away from electrical equipment
- confirm that service tools and PPE are physically nearby
- make sure the operator can identify clean-side versus dirty-side components quickly

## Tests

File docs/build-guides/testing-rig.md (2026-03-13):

# Test Rig

The test rig is separate from the treatment machine itself. Its job is to compare modules and procedures under controlled conditions so changes are based on data instead of memory.

## Use Cases

- compare two pumps under the same head and flow conditions
- measure pressure drop across candidate filter housings
- test fouling behavior with different pre-separation strategies
- validate alarms and control thresholds before field deployment

## Rig Requirements

- stable feed reservoir
- repeatable plumbing geometry
- simple isolation valves
- instrument mounts for temporary sensors
- a logging sheet or digital logger that captures each run

## Recommended Run Record

| Field | Example |
|---|---|
| Test ID | `TR-2026-03-13-01` |
| Source water | pond water after coarse screening |
| Module under test | 5 micron sediment cartridge |
| Starting pressure drop | 1.2 psi |
| Ending pressure drop | 4.8 psi |
| Flow rate | 2.1 L/min |
| Observation | visible fouling by fine clay, no leaks |

## Bias to Avoid

Do not compare modules under changing source water without noting it. Test rigs only help when the conditions are captured honestly.

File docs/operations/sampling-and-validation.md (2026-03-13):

# Sampling and Validation

If the project cannot show what changed between inlet and outlet, it is not engineering yet. Sampling plans are part of the machine design.

## Minimum Sampling Points

- raw source water
- after bulk solids removal
- after fine filtration
- final outlet or storage point

## Record for Every Sample

| Field | Why it matters |
|---|---|
| time and date | tracks drift over the run |
| machine revision | avoids mixing results across hardware changes |
| source description | water quality may vary by location and season |
| flow rate | treatment performance is often flow-dependent |
| observed turbidity, color, odor | fast field context even when lab data comes later |
| operator notes | captures anomalies that instruments miss |

## Validation Mindset

Use the simplest metric that answers the current question, then expand as the design matures:

- turbidity or optical clarity trends for solids handling
- pressure rise for fouling behavior
- treated volume before service for maintenance planning
- source-specific lab tests when the target use case requires them

## Common Failure

Sampling only when the machine is freshly cleaned produces misleading optimism. Include dirty-state and end-of-run measurements.

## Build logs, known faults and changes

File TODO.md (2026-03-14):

# TODO

Last updated: 2026-03-13

## Completed

- [x] Initialize the repository, copy the `sloppy.wiki` setup pattern, and push the initial OpenSling MkDocs scaffold.
- [x] Add repo norms for TODO tracking, licensing intent, and commit-after-task workflow.
- [x] Research and verify Slingshot history, public specs, and current disease-burden numbers from primary sources.
- [x] Rewrite the landing page around Slingshot history, current urgency, and OpenSling’s open-source mission.
- [x] Add a Slingshot reference section with a verified-specs page.
- [x] Add a high-level assembly page for the OpenSling reference build.
- [x] Add main component pages for the evaporator/condenser core, vapor compression stage, demister/volatile control, feed and blowdown loop, and controls/power/frame.
- [x] Update navigation and internal cross-links for the new section.
- [x] Run a strict MkDocs build after the research/content chunk.
- [x] Add a fabrication pack with editable CAD sources plus STL exports for the custom non-pressure parts currently defined.
- [x] Run a strict MkDocs build after the fabrication chunk.
- [x] Fix GitHub Pages deployment to use the official workflow-based Pages path for `opensling.org`.
- [x] Update `AGENTS.md` with recursive self-improvement rules, verified commands, deployment lessons, and collaborator cues.
- [x] Add a builder-facing alpha BOM with live supplier examples, a clearer build flow, and explicit missing-piece callouts.
- [x] Fix dead vendor links in the alpha BOM and make external links open in a new tab.
- [x] Replace copyright-style messaging with explicit CC BY 4.0 and Apache-2.0 reuse language across the site and repo docs.
- [x] Add a proper Open Graph and Twitter preview image plus metadata overrides for better link thumbnails.

## In Progress

- [ ] Expand the fabrication pack with pressure-safe metal drawings once the reference dimensions and materials are validated.

## Next

- [ ] Add first-pass clean-water commissioning and hydrotest procedures for the first OpenSling distiller alpha build.
- [ ] Freeze the pressure-core geometry enough to publish a real shell, heater, and sensor-port drawing set.

## Commit Log

- [x] `651c586` `Initial OpenSling wiki scaffold`
- [x] `f4e58d0` `Add repo norms and progress tracking`
- [x] `b0ec115` `Add Slingshot research and reference pages`
- [x] `07265ab` `Add fabrication pack for reference build`
- [x] `5551d97` `Fix Pages deployment for opensling.org`
- [x] `bfcb0b7` `Strengthen AGENTS recursive improvement guidance`
- [x] `a50ca93` `Add alpha BOM and builder flow`
- [x] `95656bf` `Fix vendor links and external link behavior`
- [x] `ae828b9` `Clarify open licensing across site`

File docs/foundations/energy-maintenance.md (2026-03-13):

# Energy and Maintenance Tradeoffs

Water treatment hardware is usually constrained by maintenance long before it is constrained by theory. Energy and service burden should be considered together.

## Tradeoff Table

| Choice | Strength | Cost |
|---|---|---|
| Larger pre-separation volume | reduces filter fouling | adds bulk and slower startup |
| Higher-pressure fine filtration | better particulate control | more pump power and more complex leak management |
| UV disinfection | no chemical residual | needs clear water, power, and lamp maintenance |
| Carbon polishing | improves taste and odor | consumable replacement and uncertain performance on all chemistries |
| Solar-backed system | off-grid operation | variable duty cycle and battery management overhead |

## Maintenance Reality

When comparing designs, ask:

- how often does an operator touch the machine?
- what parts clog first?
- can the service task be done without contaminating the clean side?
- how many tools are required?
- what happens if service is skipped for a week?

## Useful Biases

- spend volume and plumbing on upstream solids management
- keep consumables standardized
- make the dirty side physically obvious
- expose maintenance intervals as checklists, not tribal knowledge

## Power Budget Categories

| Category | Example loads |
|---|---|
| Always on | controller, telemetry, low-power sensors |
| Duty cycled | pumps, valves, UV chamber |
| Rare events | flush solenoids, alarms, work lights |

Documenting the power budget alongside the maintenance budget makes it easier to design systems that actually stay deployed.

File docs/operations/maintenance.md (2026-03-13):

# Maintenance and Failure Modes

Maintenance is not what happens after the design is finished. The maintenance path is part of the design.

## Service Cadence Template

| Interval | Typical tasks |
|---|---|
| Before each run | inspect hoses, power wiring, valves, and drains |
| Daily | flush solids traps, log pressures, inspect leaks |
| Weekly | replace or clean sacrificial filters as needed, inspect connectors |
| Monthly | review fouling trends, inspect pump wear items, verify sensor calibration |

## Failure Modes Worth Tracking

- intake clogging
- air ingress on suction side
- pump cavitation or overheating
- filter bypass due to bad seals
- pressure creep from fouled cartridges
- UV failure, low intensity, or contact-time mismatch
- cross-contamination during maintenance

## Good Maintenance Design

- hand-accessible service points
- drains that do not soak the electronics bay
- plain labels on consumables and replacement intervals
- enough physical room to inspect seals before closing the system

## Failure Report Template

1. what failed
2. how the issue was detected
3. what the operating state was at the time
4. immediate containment or recovery step
5. design or procedure change proposed next

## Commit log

2026-03-14 Add fabrication pack for reference build
    [blower_mount_spacer.scad, blower_mount_spacer.stl, control_panel_blank.scad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]
2026-03-14 Add alpha BOM and builder flow
